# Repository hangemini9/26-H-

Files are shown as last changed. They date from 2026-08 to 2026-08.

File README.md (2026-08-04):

# 26-H- 车载平衡滚球控制系统

本仓库包含 2026 年电赛小车滚球控制系统的两套嵌入式固件。系统采用三主控协作架构：TI 底盘负责循迹与运动执行，MC02 负责云台、电机安全状态机与调度，并可与上位视觉计算单元联动。

> 注意：本项目涉及电机、锂电池和机械运动。首次上电或调试时，请断开电机供电、抬起驱动轮，并遵循各子项目中的接线与调试说明。

## 项目结构

| 目录 | 平台 | 职责 |
| --- | --- | --- |
| [`mspm0dache/`](mspm0dache/) | TI LP-MSPM0G3507 | 后驱差速底盘控制、编码器闭环、八路循迹传感器、OLED 显示，以及与 MC02 的串口通信。 |
| [`gimbal_MC02/`](gimbal_MC02/) | STM32H723 / 达妙 MC-Board02 | DM-J4310 云台控制、CAN 通信、USB CDC 调试接口、供电安全保护，以及与 TI/Jetson 的协议接口。 |

## 系统协作关系

```text
Jetson（视觉/上位机）
        │ USB CDC
        ▼
MC02（STM32H723） ───── UART ───── TI 底盘（MSPM0G3507）
        │ CAN                              │ PWM / 编码器 / I²C
        ▼                                  ▼
DM-J4310 云台电机                    差速驱动电机、循迹传感器、OLED
```

## 快速开始

### 底盘固件：`mspm0dache`

该项目使用 TI MSPM0 SDK 与 TI Clang 工具链。打开项目目录后，可在 VS Code 中选择构建任务，或使用：

```powershell
C:\ti\ccs\utils\bin\gmake.exe -C . -j4
```

详细的编译、下载、接线和首次标定说明见：

- [`mspm0dache/README.md`](mspm0dache/README.md)
- [`mspm0dache/COMMISSIONING.md`](mspm0dache/COMMISSIONING.md)
- [`mspm0dache/调试与标定指南.md`](mspm0dache/调试与标定指南.md)

### 云台固件：`gimbal_MC02`

该项目使用 CMake、Ninja 和 `arm-none-eabi-gcc`。在项目目录下执行：

```powershell
cmake --preset Debug
cmake --build --preset Debug
```

生成的调试产物位于 `build/Debug/`。调试下载使用 J-Link/Ozone；完整的接线与安全上电流程见：

- [`gimbal_MC02/README.md`](gimbal_MC02/README.md)
- [`gimbal_MC02/docs/MC02_WIRING_CHECKLIST.md`](gimbal_MC02/docs/MC02_WIRING_CHECKLIST.md)
- [`gimbal_MC02/docs/MC02_TI_PROTOCOL_V2.md`](gimbal_MC02/docs/MC02_TI_PROTOCOL_V2.md)
- [`gimbal_MC02/docs/JETSON_MC02_PROTOCOL_V3.md`](gimbal_MC02/docs/JETSON_MC02_PROTOCOL_V3.md)

## 协议与安全

- MC02 与 TI 底盘通过 UART 进行状态与任务控制通信。
- MC02 与云台电机通过 CAN 通信，并在上电、使能、故障和超时路径中实施保护。
- 底盘固件支持编码器、循迹传感器和通信链路的安全监测；异常时会停止并解除电机使能。
- 任何带电运动测试前，都应先完成无负载验证，并保留随时切断主电源的能力。

## 说明

各子项目的 README 是对应硬件与固件的权威操作说明。本文档用于介绍仓库整体结构；具体引脚、构建环境、协议帧和调参方法请以子项目文档为准。

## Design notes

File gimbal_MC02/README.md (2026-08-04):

# gimbal_MC02

达妙 DM-MC-Board02（STM32H723VGT6）控制 DM-J4310-2EC V1.2 的云台固件。
当前版本只面向桌面安全联调；视觉闭环、五项现场测试状态机和 TI 底盘通信均未启用。

## 当前固定配置

- 电机：DM-J4310-2EC V1.2，24 V，减速比 10:1
- 电机模式：位置速度模式
- CAN：经典 CAN、标准帧、1 Mbit/s
- 电机 CAN ID：`0x01`
- 电机 Master ID（反馈帧 ID）：`0xF1`
- MC02 电机 CAN：FDCAN1，PD0=RX、PD1=TX
- Jetson 链路：MC02 USB CDC；接口定义见
  [`docs/JETSON_MC02_PROTOCOL_V3.md`](docs/JETSON_MC02_PROTOCOL_V3.md)，build `2026073106` 已实现
- TI 底盘链路：接口定义见
  [`docs/MC02_TI_PROTOCOL_V2.md`](docs/MC02_TI_PROTOCOL_V2.md)，当前为 MC02 `2026080107`（按用户要求回退第二问，其他问保留）与 TI `2026080104`；五问题号路径、K6底盘软件动力许可、加减速斜坡前馈、停车后至少五秒达妙闭环保持和三秒最终稳定握手均已实现
- 编译：VSCode + CMake + Ninja + arm-none-eabi-gcc
- 调试/下载：J-Link + Ozone，SWD，4 MHz

完整接线和分阶段上电清单见
[`docs/MC02_WIRING_CHECKLIST.md`](docs/MC02_WIRING_CHECKLIST.md)。

依据 MC02 V1.1 原理图，PC14/PC13 分别控制 OUT1/OUT2 的高边电源。构建
`2026073008`在启动时明确保持两路关闭；OUT2始终关闭。常规接口只允许通过
`PWRARM 4310`后3秒内发送`PWRON`开启OUT1；人工调试开关启用时，
`CALRUN 4310 deg`会在同一安全状态机内完成一次受限上电测试。冷启动阶段会在保持转矩禁用的前提下
持续请求反馈，最多等待15秒。OUT1最多开启300秒，`STOP`、`PWROFF`、
任意故障、非JOG动作超时或复位都会立即关闭。JOG超时会失能并回到OBSERVE，
但保持同一供电周期的电机角度坐标。第一次必须断开电机，在空载状态下
分别验证OUT1关闭和开启电压。

## 编译

在 VSCode 中打开本目录，然后运行默认生成任务 `MC02: Build Debug`；或在终端运行：

```powershell
cmake --preset Debug
cmake --build --preset Debug
```

产物：

```text
build/Debug/gimbal_MC02.elf
build/Debug/gimbal_MC02.hex
build/Debug/gimbal_MC02.bin
```

全环路延迟测量必须使用独立的 `DelayTest` 预设，构建、Ozone 请求顺序和
强制空载验证见
[`docs/DELAY_TEST_FIRMWARE.md`](docs/DELAY_TEST_FIRMWARE.md)。该镜像不是比赛固件。

Ozone 打开 `gimbal_MC02.jdebug`，下载并复位运行。MC02 四针 SWD 插座按
说明书为：1=3.3 V/VTref、2=GND、3=SWCLK/PA14、4=SWDIO/PA13；该插座没有
NRST。不要用 J-Link 给 MC02 或电机供电。

## 上电安全行为

- 上电后状态为 `SAFE_IDLE`，不会自动使能电机。
- OUT1/OUT2上电默认关闭，OUT2没有开启路径。
- 常规OUT1供电需要`PWRARM 4310`与`PWRON`两步操作；人工调试`CALRUN`
  是常规 Debug 的受限例外。独立 `DelayTest` 构建另有专用 Ozone 解锁和
  空载确认流程；两者都只能在对应编译开关启用、SAFE_IDLE和无故障时启动。
- OUT1开启后等待500 ms，再发送5帧失能命令；完成前拒绝`OBSERVE`和运动。
- 启动时发送 5 帧失能命令，然后停止周期控制。
- 任何动作必须先收到新鲜 CAN 反馈，再执行一次性 `ARM`。
- `ARM` 只保留 3 秒，动作开始后立即失效。
- 当前角度被捕获为本次测试的局部零点。
- 最大相对角度固定为 ±10.0°。
- 位置速度模式的 `v_des` 固定为 0.20 rad/s。
- HOLD、STEP、SWEEP 分别在 15、3、6 秒后自动失能。
- 动作中 80 ms 没有电机反馈，立即进入故障并失能。
- 电机反馈状态不是 0（失能）或 1（使能）时，立即进入故障并失能。
- `STOP` 不需要解锁，任何时候都可执行。
- `STOP`、故障、非JOG动作超时和复位同时关闭OUT1；JOG超时失能并返回OBSERVE，
  OUT1仍受300秒总超时保护。

电机带电运动时不要让 CPU 停在断点；暂停 CPU 会同时暂停 CAN 心跳和软件保护。

## 桌面调试顺序

先固定电机和机构，保证 ±10° 内没有机械干涉，手能立即断开总电源。第一轮建议
先不装水管或移除钢球。

1. 在达妙助手确认模式、CAN ID、Master ID 和 1 Mbit/s。CAN Timeout 暂时保持 0。
2. 电机2+2插头保持断开，刷入 Debug ELF，复位后持续运行。
3. Ozone Watch 添加 `g_gimbal_debug`。应看到：
   - `build_id = 2026073008`
   - `state = 1`（SAFE_IDLE）
   - `fault = 0`
   - `can_tx_count` 启动后至少增加 5
   - `power_output_enabled = 0`
4. 第一次验证OUT1时保持电机2+2插头断开。发送`PWRARM 4310`后，在3秒内
   发送`PWRON`。测量空载OUT1应从约0 V变为主输入电压，并在300秒后自动回到
   约0 V。也要分别验证`PWROFF`和`STOP`能立即关闭OUT1。任一项不符合都不得
   连接电机。
5. 空载供电验证通过后，断电连接2+2电机线，再打开MC02 USB虚拟串口。
   USB CDC的终端波特率设置不影响链路，习惯上可选
   115200、8N1。依次发送：

```text
PWRARM 4310
PWRON
PING
OBSERVE
STATUS
```

`PWRON`后至少等待600 ms再发送`OBSERVE`，让电机启动并完成5帧失能命令。
`OBSERVE` 每 20 ms 发送位置速度模式失能帧来请求反馈，绝不使能电机。`STATUS` 应出现
`ONLINE=1`、`RX` 持续增加；失能时 `ERR=0x0`。若无反馈，不要继续动作测试。
如果 OBSERVE 收到状态1（使能）或任意故障反馈，固件会立即关闭 OUT1 并进入故障状态。

6. 第一次动作只做当前位置保持：

```text
ARM
HOLD
```

电机应转为绿色使能，但不应主动大幅转动；15 秒后自动失能。

7. 再做最小正反向测试：

```text
OBSERVE
ARM
STEP 0.5
OBSERVE
ARM
STEP -0.5
```

确认正负方向、反馈角度、机构刚度和电流正常后，才逐步增加到 1°、2°，最大 3°。

8. 最后才测试：

```text
OBSERVE
ARM
SWEEP 1.0
```

紧急停止命令：

```text
STOP
```

故障排除后发送 `CLEAR`，只会清故障并保持失能，不会恢复动作。

## 安装机构快速标定

坐标约定固定如下：钢球位置以中心 O 为零，朝电机所在的物理左端为正，朝铰链所在
的物理右端为负。水管角度则以水平为零、电机端升高为正、电机端降低为负。因此
当前机构的正电机偏移对应负水管角，并使钢球朝左侧正方向加速。日志中的
`CALRUN +deg`始终表示电机角度，不表示水管角度。
手机水平仪初测表明电机±45°对应水管倾角约∓2°，第一版映射可暂按
`水管角度≈-0.044×电机角度`使用，但必须保留为可调参数并由视觉闭环继续标定。

构建 `2026073008` 的下一项无球机构测试只使用一条命令：

```text
CALRUN 4310 45
```

发送前必须取出钢球、把水管置于水平、确认机构周围无人手或工具，并保证能够
随时断开总电源。该命令自行开启OUT1、等待电机反馈，提示后倒计时3秒，然后自动
以不超过0.20 rad/s执行`+45° -> 0° -> -45° -> 0°`，每段最多5秒并输出
起点、零点、目标和终点，最后失能并
关闭OUT1。任意阶段发送`STOP`都会立即中止并关闭OUT1。幅度参数只允许
0.1～45°。
构建`2026073008`修复了旧版运动循环仍二次限制在±10°的问题；本轮正确的两个
端点日志应接近`OFF=+785mrad`和`OFF=-785mrad`。若仍只出现约±174 mrad，
说明运行的不是修复后的固件，不得把它记为±45°测试通过。

这是纯人工桌面调试功能，由
`GIMBAL_ENABLE_MANUAL_CALRUN`控制。当前 Debug 调试构建为`1`；正式上车直接使用
`cmake --preset Vehicle`和`cmake --build --preset Vehicle`，该预设会可靠地把
`GIMBAL_MANUAL_CALRUN`设为`OFF`，使`CALRUN`只返回禁用提示。

如果15秒内仍没有电机反馈，流程会关闭OUT1并直接返回SAFE_IDLE，修复问题后可重新发送同一条命令，
无需先CLEAR。原有`ZERO/JOG/STEP/SWEEP`仍保留为底层单项诊断接口，并继续限制在
±10°和原有超时；只有人工CALRUN允许±45°和5秒单段。构建 `2026073008` 不改变
0.20 rad/s速度、80 ms反馈看门狗和断电保护。

先取出钢球，让底盘和水管处于水平状态。电机进入 `OBSERVE` 且反馈正常后发送：

```text
ZERO
STATUS
```

`ZERO`记录当前电机反馈为本次上电的水管水平零点。`STATUS`中的
`ZVALID=1`表示有效，`Z`是水平零点，`OFF`是当前电机相对水平零点的偏移。
随后发送：

```text
ARM
JOG 10
```

`JOG`始终以保存的水平零点为基准，而不是以每次动作前的位置为基准。
它仍然需要3秒内的`ARM`，并在3秒后失能、返回`OBSERVE`，但不切断OUT1，
以避免DM4310重启改变位置坐标。负向测试使用`JOG -10`。固件会自动报告
FROM、Z、TARGET以及动作结束时的P和OFF。为保证坐标一致，构建`2026073008`
会在STOP、故障、PWROFF、
300秒超时或其他OUT1掉电事件时自动作废零点，之后必须重新执行`ZERO`。
MC02复位同样会清除零点。

## Ozone 直接调参/触发

核心观测变量只有一个：`g_gimbal_debug`。状态和请求枚举见
`Core/Inc/gimbal_app.h`。

不要通过Ozone直接写PC14或GPIO寄存器开启OUT1。供电只允许使用USB命令。

直接触发云台动作时：

1. 将 `arm_key` 写为 `0xA55A5AA5`；
2. STEP/SWEEP 时把 `request_param_tenths_deg` 写成角度的 0.1° 单位，
   例如 `5` 表示 0.5°；
3. 最后写 `request`：STOP=1、OBSERVE=2、HOLD=3、STEP=4、SWEEP=5、
   CLEAR=6。

固件会消费并清零 `arm_key` 与 `request`。推荐先用 USB 命令完成首轮测试；
Ozone Watch 用于观察状态和后续快速调参。

## 目前还需要的实测信息

- 电机接到 MC02 的具体 FDCAN 口、CANH/CANL 和终端电阻实测；
- `STEP +10` 时水管实际顺/逆时针方向，用于冻结控制符号；
- 水管机械水平时的电机反馈角，以及本轮 ±45° CALRUN 端点的反馈角；
- build `2026072903`下OUT1空载关闭/开启/30秒超时/PWROFF/STOP的实测电压；
- 使用OUT1给DM4310供电时的6S电池电压、峰值电流和MC02输出温升。

构建 `2026073008` 保留已经验证的桌面 ±10° 限幅，并新增单指令标定，但这些量确认前仍不
启用视觉闭环，也不继续提高到 ±10° 以上。

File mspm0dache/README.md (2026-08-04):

# mspm0dache

MSPM0G3507 LaunchPad rear-drive differential-chassis firmware.

The chassis has two MG513XP28_12V drive motors at the rear and two passive
casters at the front. The first firmware is intentionally a safe commissioning
and calibration build. The current download path uses the LaunchPad onboard
XDS110 through its Micro-USB connector. Build 2026080104 implements all
eight button inputs and all five MC02 V2 question paths while keeping
standalone motion disabled. K1/K3/K4/K5 start their assigned chassis route
only after PREPARE/READY/START; K2 reports logical RUNNING while both PWM
outputs remain disabled for the stationary ball task. Q1 alone uses the
front line-sensor row as the final A datum through a bounded forward-align,
settle and reverse-marker sequence. Q3 stops after the measured 1.5 m A-B
straight; Q4/Q5 finish one lap without reversing. Q3/Q4/Q5 use a gentler
common-speed ramp while retaining fast steering correction. Q1 uses a
40-second safety timeout with a 143 RPM straight target and 110 RPM curve
floor, exactly 10% above the previous Q1 profile, to preserve the scored goal
of finishing within 20 seconds. No Q2-Q5 speed or ramp is changed.

中文上手说明见 [调试与标定指南.md](调试与标定指南.md)。
逐线硬件连接见 [接线指导.md](接线指导.md)。

Mechanical reference: [docs/R3X_chassis_320x240mm.pdf](docs/R3X_chassis_320x240mm.pdf).
The source PDF title says "four-wheel differential", but this firmware follows
the confirmed physical configuration of two driven rear wheels and two passive
front casters.

## Confirmed hardware

| Item | Configuration |
|---|---|
| MCU | LP-MSPM0G3507 |
| Motor driver | SeekFree dual-channel DRV8701E, PH/EN interface |
| Motors | 2 x MG513XP28_12V, nominal 1:28 gearbox |
| Encoders | 13 PPR quadrature Hall, measured left 1467/right 1468 counts/wheel revolution |
| Wheel diameter | 65.0 mm |
| Drive-wheel track | 214.2 mm, center to center |
| Front/rear axle spacing | 204.7 mm, metadata only |
| Tire contact width | 25.5 mm |
| Battery | 6S LiPo through regulated power conversion |
| Debug/download | LaunchPad onboard XDS110 through Micro-USB |
| Bluetooth | JDY-31 unplugged; UART0 code/config temporarily disabled |
| External button | SW1 active low on PA10/BP33 with MCU internal pull-up |
| Line sensor | Hiwonder LineFollower_8CH V1.0, 5 V supply, I2C address 0x5D |
| OLED | GM009605-class 128x64 I2C module, 3.3 V supply, address probe 0x3C then 0x3D |
| IMU | ICM42688 API placeholder only; disabled and no pins assigned |

## Build

Installed tool paths used by this project:

```text
C:\ti\mspm0_sdk_2_10_00_04
C:\ti\sysconfig_1.28.0
C:\ti\ccs\tools\compiler\ti-cgt-armllvm_5.1.1.LTS
C:\ti\ccs\utils\bin\gmake.exe
```

In VS Code, press `Ctrl+Shift+B` and select `Build MSPM0 (TEST_MODE)`, or run:

```powershell
C:\ti\ccs\utils\bin\gmake.exe -C . -j4
```

Run the complete offline verification (clean TEST_MODE build, release build,
configuration checks, ELF symbol checks, and memory report) with:

```powershell
C:\ti\ccs\utils\bin\gmake.exe -C . verify
```

The debugger-loadable ELF output is:

```text
ticlang\mspm0dache.out
```

To build and download the TEST_MODE firmware through the onboard XDS110,
select `Build and Flash MSPM0 (onboard XDS110)` in VS Code, or run:

```powershell
C:\ti\ccs\utils\bin\gmake.exe -C . flash
```

Keep all J101 jumpers in their factory-installed positions, connect only the
LaunchPad Micro-USB debug connector, and leave J102/J103 unused. CCS `DSLite`
performs the download. SEGGER Ozone does not control XDS110; use the CCS
debugger Expressions view when live writes to `g_test` are required. Source
editing and Makefile builds remain in VS Code.

### Live parameter tuning

The VS Code flash task exits after programming, so it cannot display or edit
live target variables. Run the VS Code task `Open CCS Live Tuning`; it opens
this same folder in the installed CCS 21 Theia application. In CCS:

1. Open Run and Debug.
2. Select `MSPM0G3507 XDS110 Live Tune` and start debugging.
3. If execution stops at `main`, press Continue.
4. Open the Expressions view and add only `g_test`.
5. Keep the target running and edit values in Expressions. Do not use
   breakpoints while motor power is connected.

The CCS launch configuration is `.theia/launch.json`. It loads
`ticlang/mspm0dache.out` through the onboard XDS110 and keeps the debug session
attached.

Build 2026080104 allows an intact, fresh sensor to report no active channel
during Q1's bounded straight reverse; sensor disconnect/staleness still
faults. The final marker still requires three simultaneous channels in three
fresh samples. TI also advertises commanded common acceleration/deceleration
in V2 status bits 10/11 so MC02 disables chassis feed-forward during steady
cruise. The OLED retries initialization once per second after runtime I2C
loss. Full clean verification results are recorded in `AGENT.MD`; they do not
replace powered floor commissioning.

The default build passes `TEST_MODE=1` and uses `-O0 -gdwarf-3` so global
variables remain easy to inspect. `gmake release` produces a build with the
test command executor disabled as `ticlang\mspm0dache_release.out`; that
build remains stopped because no production command source has been selected
yet.

## Pin assignment

| Function | MSPM0G3507 pin |
|---|---|
| Right motor PWM / DRV PWM1 | PA12 / TIMG0_CCP0 |
| Right motor direction / DRV DIR1 | PB4 |
| Left motor PWM / DRV PWM2 | PA13 / TIMG0_CCP1 |
| Left motor direction / DRV DIR2 | PB1 |
| Right encoder A/B | PB6 / PB7, J2 BP13/BP14, TIMG8 QEI |
| Left encoder A/B | PB16 / PB0, J2 BP11/BP12, GPIO both-edge IRQ |
| External button-panel SW1 | PA10 / BoosterPack 33, active low, internal pull-up |
| Temporarily unused | PA11 / BoosterPack 34 |
| Hiwonder line sensor SCL | PB2 / I2C1 SCL / BoosterPack 9 |
| Hiwonder line sensor SDA | PB3 / I2C1 SDA / BoosterPack 10 |
| OLED SCK/SDA | shared PB2/PB3 I2C1 bus with the line sensor |
| MC02 supervisor TX | PA8 / UART1 TX / J1_4 |
| MC02 supervisor RX | PA9 / UART1 RX / J14_3 |

The JDY-31 is unplugged and UART0 is not generated or linked in this build.
The retained `bluetooth.c/.h` and PC helper are inactive reference code.
Only button-panel SW1 is assigned; SW2-SW8, onboard S2, PA11, buzzer, and
ICM42688 control are unused. UART1 uses 115200 8N1 on PA8/PA9 for the MC02
binary supervisor link.

Expand `g_test.line` to observe `connected`, `sample_sequence`, `error_count`,
the eight-bit `state`, `active_count`, `line_lost`, `position_x1000`, and the
eight `analog[]` and `threshold[]` values. `position_x1000` is negative toward
S1/vehicle-left and positive toward S8/vehicle-right; one adjacent-sensor
spacing is 1000. Its value is invalid whenever `line_lost` is 1.
TEST_MODE build 2026080104 provides guarded competition line following as
mode 8. It uses `base_rpm` and `steering_kp`; `correction_rpm` and the two
wheel targets are telemetry. `steering_kd` damps residual heading after a
turn. `lap_phase` exposes the Q1 competition sequence, `lap_distance_mm`
reports total run travel, `turn_count`/`lap_yaw_deg` report the private
encoder-yaw turn estimate, and `finish_distance_mm` reports forward-align
distance in phase 3 and reverse distance in phase 5.
`marker_recent_state/count` expose the 120 ms reverse-search channel union as
diagnostics only. For Q1, a reverse marker candidate requires at least three
channels simultaneously active in three consecutive fresh samples,
preventing a drifting ordinary one/two-channel line from being accumulated
into a false marker. Q3/Q4/Q5
never enter the Q1 reverse phases. Their average/common wheel request uses
30 RPM/s for Q3 and 14 RPM/s for Q4/Q5 acceleration and deceleration slew;
their differential steering request retains a 300 RPM/s slew so gentler ball
handling does not make curve correction unresponsive. Q3 begins its gentle
stop at 1500 mm; Q4/Q5 use 70 RPM cruise and begin
the same stop after the existing two-turn/distance lap gate.

The OLED stopwatch starts when the accepted MC02 START reaches actual Q2
execution or, for a moving question, when the fresh-sensor gate succeeds and
the motor controller is armed. It updates once per second while running and
freezes when the chassis run ends. The value is rendered beside `TIME` as
three decimal seconds plus `S`; only the displayed three digits wrap after
999 seconds, while the internal timer never wraps there. Each change is
written as one complete four-character refresh. If three consecutive runtime
OLED writes fail, the display reconnects and redraws automatically once per second. A
K1-K5 press by itself no longer starts the displayed timer.
The first test must use raised drive wheels.
Sensor disconnect or stalled sampling removes drive immediately and faults
within 100 ms. Outside Q1 reverse, a line-only loss uses the last valid side
to search at reduced speed for at most 300 ms, then stops and disarms with
status -6. During Q1's bounded straight reverse, zero active channels does
not stop the reverse; the existing 400 mm/6 s bounds remain authoritative.
The first 50 ms of other line loss holds prior targets. Line position uses a
0.25 low-pass factor before curve-speed and PD calculation.
Before connecting PB2/PB3, power the sensor from its regulated 5 V rail with
common ground and measure idle SCL/SDA to ground. Connect them directly only
if both are no higher than 3.3 V; otherwise use a bidirectional I2C level
shifter. Do not power the sensor from J11 3V3.

## Debugger test workflow

Download with the VS Code XDS110 task above. For all commissioning control
and telemetry, attach CCS through the same onboard XDS110 and add only the
single expression `g_test`, then expand it. Set `duration_ms`, `target_rpm`,
and `left/right.kp/ki/kd` only while stopped. Encoder counts, RPM, error,
applied PWM, PID integral/output, button/countdown state, and safety faults
update inside the same structure. Line-sensor telemetry is under
`g_test.line`. The legacy
[mspm0dache.jdebug](mspm0dache.jdebug) file is retained only in case J-Link is
used again later.

Reset state is always:

```text
g_test.mode = 0
g_test.arm = 0
both PWM outputs = 0
```

For every motion command:

1. Set all parameters first.
2. Set `g_test.arm = 1`.
3. Set `g_test.mode` last.
4. The firmware consumes and clears `arm`.
5. It stops and disarms at completion or timeout.

Setting `g_test.mode = 0` also stops and disarms within the 10 ms task period.

| mode | Operation | Needs arm |
|---:|---|:---:|
| 0 | Stop/disarm | No |
| 1 | Stop and observe encoder telemetry | No |
| 2 | Reset both encoder totals | No |
| 3 | Right wheel only, positive open-loop PWM | Yes |
| 4 | Left wheel only, positive open-loop PWM | Yes |
| 5 | Both wheels positive open-loop PWM | Yes |
| 6 | Both wheels negative open-loop PWM | Yes |
| 7 | Both wheels closed-loop at `target_rpm` | Yes |
| 8 | Low-speed black-line following | Yes |

Motion results:

| status | Meaning |
|---:|---|
| -6 | Line sensor disconnected/stale for 100 ms, or line not reacquired within 300 ms |
| -5 | Required motor output never started or had the wrong sign |
| -4 | A required wheel encoder did not count or stopped counting |
| -3 | Bad parameter |
| -2 | Motion timed out |
| -1 | Motion requested without `arm = 1` |
| 0 | Idle |
| 1 | Running |
| 2 | Completed |
| 3 | Start pending / fresh line-sensor validation |
| 4 | Two-turn estimate unavailable; stopped by the 6.1 m distance fallback |

Open-loop diagnostic modes use a fixed 15% PWM. `duration_ms` defaults to
20000 ms and is frozen when a run starts. Modes 3-7 are hard-limited to
30000 ms; mode 8 is separately hard-limited to 120000 ms for the long test
track. Closed-loop modes require at least 2000 ms. Output has an absolute 40%
PWM safety cap that is not debugger-writable.

Modes 7 and 8 require both encoders to show continued progress in the commanded
direction. A missing, stalled, or oppositely signed encoder stops the run.
Each wheel's first 750 ms encoder window begins only after actual PWM has
cleared any direction-change hold. Once supervision starts, it never pauses:
zero output with no continued wheel motion still faults within the window,
and a non-zero wrong-sign output faults immediately. Mode 7 must verify both
encoders for at least one complete window before reporting success; see
`encoder_verified_mask`. Output readiness/direction uses `output_fault_mask`.

`g_test.status` is output telemetry, not a control input. The timeout and
fault state machine is private, so accidentally editing `status` in a debugger
cannot suspend protection.

For the first mode-8 test, raise the drive wheels and keep the sensor at its
calibrated gap above the track. Set `duration_ms = 5000`,
`line.base_rpm = 30`, and `line.steering_kp = 6`, then set `arm = 1` and set
`mode = 8` last. A centered S4/S5 line produces equal targets. Moving the line
toward S1 makes the left target lower and right target higher; moving it
toward S8 does the opposite. Removing the line must produce status -6 and
`motor_armed = 0` after the 300 ms directional-recovery window. Disconnecting
I2C or freezing samples must remove drive immediately and fault within about
100 ms. Only after these checks pass should a short floor test be attempted.

### MC02-supervised KEY1 formal-course control

Button-panel SW1 is connected to PA10/BP33, panel VCC to LaunchPad 3V3, and
panel GND to system GND. It is active low with the MSPM0 internal pull-up,
debounced for 40 ms, and polled by the 10 ms test task. Never power panel VCC
from 5 V.

1. Press/release KEY1 once. TI sends a debounced button event to MC02. It
   neither starts the stopwatch nor arms the motors at button time.
2. MC02 sends PREPARE, waits for TI READY, uses a three-second countdown
   interval, then sends START. For moving questions TI still requires five
   newly acquired valid line
   samples within 500 ms before arming.
3. Starting on the transverse bar, the first 100 mm commands equal left/right
   targets at the slow-start speed before normal centroid steering takes
   over. The run uses 30 RPM for the first second, a 55 RPM first-300-mm cap,
   143 RPM Q1 straight cruise and 110 RPM Q1 curve floor. The course model is two
   1500 mm straights plus two radius-500 mm semicircles: 6141.6 mm nominal
   centerline length. The Q1 safety timeout is 40,000 ms while the scored
   completion target remains 20 seconds.
4. After the two-turn/distance finish gate, TI follows 150-250 mm farther
   into the next straight at 60 RPM and requires eight fresh centered
   one/two-channel samples. It commands true zero and waits for both wheels
   to settle below 2 RPM, then reverses with equal 25 RPM targets. A is
   accepted only after at least three channels are simultaneously active in
   three consecutive fresh sensor samples. The 120 ms union remains visible
   for diagnosis but does not grant stop authority. Failure
   to find A within 400 mm or 6 seconds stops as a route timeout.
5. Q1 route completion, MC02 SAFE_STOP, a fault, or a link-loss stop freezes
   the displayed integer seconds. OLED failure never grants or removes motor
   authority.

`STANDALONE_KEY1_START=0` makes PREPARE/READY/START the only motion
authority. K1-K5 select the five internal questions. K6 toggles a software
chassis-power permission only while TI/MC02 are online and idle: OLED
`PWR 0` blocks Q1/Q3/Q4/Q5, while `PWR 1` permits their later START.
Q2 remains stationary and works with `PWR 0`. SAFE_STOP, K7, K8, faults and
link loss all restore `PWR 0`; this is not a physical 12 V disconnect.
K7 is normal stop/reset and K8 is the latched emergency stop. The physical
motor-power disconnect remains mandatory during first communication tests.

Expand `g_test.mc02` for compact link telemetry: `online`, `state`, `fault`,
`run_id`, `last_command_id`, `question_id`, and RX/CRC/TX counters.

### JDY-31 Bluetooth status

The JDY-31 module has been unplugged at the user's request. UART0 and all
Bluetooth start/heartbeat/status handling are excluded from build 2026073006.
The source and helper script are retained only so Bluetooth can be restored
later. PA10 is now SW1 and must not be connected to the JDY-31 at the same
time.

The motor layer also guards direction reversal: PWM is removed, the wheel is
given at least 1000 ms to coast and must then read below 2 RPM, then the DIR
line receives a further 10 ms setup interval before PWM can resume. Encoder
feedback can never shorten the fixed 1000 ms interval.

## Mandatory first commissioning order

Read [COMMISSIONING.md](COMMISSIONING.md) before connecting motor power.
The short version is:

1. Keep the DRV8701E motor power disconnected and verify reset PWM is zero.
2. Power both encoders from verified 5 V, pass all four push-pull A/B outputs
   through proper 5 V-to-3.3 V level translation, and measure each MCU-side
   high level before connecting it to the MCU.
3. Calibrate left and right counts per wheel revolution independently.
4. Verify each PWM/DIR channel with a scope.
5. Apply regulated 12 V, lift both wheels, and start at 10-15% PWM.
6. Tune PID only after encoder scale and direction are correct.
7. Calibrate effective track using repeated in-place turns.

Do not halt the CPU at a breakpoint while motor power is enabled. A halted
core cannot execute the timeout, and a PWM timer may stop while its output is
high. Use live Expressions updates without breakpoints for powered testing.

## Source map

- `chassis_config.h`: geometry, encoder placeholders, signs, safety limits.
- `motor.c/.h`: PH/EN output, QEI/GPIO encoders, filtered RPM, PID, arming.
- `chassis.c/.h`: differential kinematics and odometry conversions.
- `test_mode.c/.h`: one-shot debugger command interface and telemetry.
- `imu.c/.h`: disabled ICM42688 placeholder.
- `mspm0dache.syscfg`: authoritative peripheral and pin allocation.
- `AGENT.MD`: handoff state for future agents and conversations.

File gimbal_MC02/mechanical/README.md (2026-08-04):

# DM4310 end-drive crank R50 V1

`DM4310_CRANK_R50_M8_V1.stl` is the recommended replacement for the supplied
low-eccentricity integral-rod parts.

## Frozen dimensions

- output hub: 35 mm diameter;
- part thickness: 10 mm;
- four motor mounting holes: 3.3 mm diameter on a 27 mm pitch circle;
- follower-pin eccentricity: 50 mm;
- follower-pin hole: 8.2 mm diameter;
- follower boss: 21 mm diameter;
- nominal hinge-to-drive distance: 220-230 mm;
- intended usable pipe tilt: approximately +/-10 degrees;
- initial motor travel for the mechanism: approximately +/-55 degrees from
  the installed neutral, subject to ball-free hardware verification.

The four mounting-hole centers are at radius 13.5 mm and angles 60, 120, 240,
and 300 degrees. This is equivalent to approximately
`(x,y)=(+/-6.75,+/-11.69) mm`, measured from the motor-output center.

## Required follower hardware

Do not print a long cantilever rod as part of the crank. Use:

- one M8 steel shoulder bolt or smooth 8 mm steel shaft;
- preferably two 688 bearings (8 x 16 x 5 mm) as the free follower roller;
- spacers and a locknut so the roller contact plane is about 18-20 mm in
  front of the printed crank;
- an upper keeper with 1-2 mm free clearance above the 20 mm OD pipe so the
  pipe cannot leave the follower during vehicle vibration.

If the hinge axis passes through the pipe centerline, a 16 mm OD follower
requires the motor axis to be about 18 mm below the hinge axis when the pipe
is horizontal and the crank points horizontally. Recalculate this height if
the final follower outside diameter or hinge offset changes.

## Printing

- print flat with the 10 mm thickness in Z, as stored in the STL;
- PETG, PA, or another tough material is preferred over brittle PLA;
- use at least 6 walls and 60% infill; use 100% infill around the follower
  boss if the slicer supports modifier regions;
- inspect all four motor holes and the M8 follower hole before installation;
- do not perform the first powered test with a ball installed.

The generator is `generate_dm4310_crank.py`. It requires `trimesh`, `shapely`,
and `mapbox_earcut`.

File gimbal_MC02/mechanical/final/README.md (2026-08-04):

# Final printed gimbal crank

User-frozen on 2026-07-30:

```text
PITCH_FINAL_R15P45_R3_20260730.STL
```

Original source:

```text
C:\Users\Han\Desktop\dIANSAI\PITCH_NEW_RPLUS7_R3_CONTAINED.STL
```

Integrity:

```text
size:   768984 bytes
SHA256: 010919C1A376811A5C7BEDD237305554FC9CF96A3D4154B04B5BBF57FD02E3F5
```

The source and project backup were byte/hash verified identical.

## Measured STL geometry

- binary STL, 15,378 triangles;
- one connected watertight component;
- overall bounds approximately 49 x 75 x 49 mm;
- circular mounting base diameter: 49 mm;
- four mounting holes: diameter 3.2 mm on a 27 mm pitch circle;
- integral follower rod: diameter 12 mm;
- follower-axis eccentricity from motor axis: **15.45 mm**;
- R3 contained transition is present;
- mesh volume: approximately 17,263 mm^3.

This is the final physical print selected by the user. Earlier 25 mm and
50 mm crank proposals and `mechanical/DM4310_CRANK_R50_M8_V1.stl` are
superseded and must not be used for firmware geometry.

## Firmware constants still pending installation

Use the fixed crank radius:

```text
crank_radius_mm = 15.45
```

Do not finalize the motor-to-pipe mapping until these installed values are
measured:

- hinge-axis to follower contact distance `L`;
- motor feedback angle at a level pipe;
- installed motion sign;
- usable motor-angle endpoints before contact loss or collision.

Installed measurements reported on 2026-07-30:

- DM4310 axis is 1 mm above the hinge axis;
- pipe midpoint to follower station is 115 mm;
- pipe midpoint to hinge axis is 133 mm;
- direct hinge-to-follower distance was separately reported as 236 mm.

The two midpoint dimensions imply 248 mm, which conflicts with 236 mm by
exactly the nominal 12 mm follower diameter. Do not use either as the final
`L` until the hinge-axis to DM4310-output-axis center distance is directly
remeasured. The physical pipe endpoints are +/-125 mm from O and the scored
positions are +/-50 mm.

The geometric absolute pipe-angle limit is
`asin(15.45 / L)`. Representative values are approximately:

| L | Absolute geometric limit |
|---:|---:|
| 180 mm | 4.92 deg |
| 220 mm | 4.03 deg |
| 230 mm | 3.85 deg |

No firmware behavior is verified merely by freezing this STL.

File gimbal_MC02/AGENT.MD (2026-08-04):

# gimbal_MC02 canonical handoff

Last updated: 2026-08-01

## 2026-08-01 user-requested rollback from build 0108 to 0107

- At the user's explicit request, the untested build `2026080108` Q2 energy
  schedule was removed and MC02 Vehicle was restored exactly to Q2 build
  `2026080107`: 350 ms positive breakaway, 1.8-degree stationary positive
  request, no forced raw-30-mm brake, no centre-crossing drive floor, and a
  20 mm final-capture entry with the +1.0-degree negative drive cap.
- Q1 and accepted Q3-Q5 behavior remain unchanged. TI stays at build
  `2026080104`; Jetson V3 and TI V2 packet formats and meanings are unchanged.
  Full clean Debug/Release/Vehicle/DelayTest verification passed at
  111340/716/13964, 69876/712/13952, 69588/712/13952 and
  113932/716/14028 text/data/BSS bytes. Powered behavior remains to be tested.

## 2026-08-01 Q2 data-driven asymmetric energy schedule

- MC02 Vehicle build `2026080108` changes only Q2. TI remains build
  `2026080104`; Q1 and the accepted Q3-Q5 controller/route behavior are
  unchanged, and neither Jetson V3 nor TI V2 packets changed.
- The supplied multi-run extraction contains eight active Q2 attempts. Two
  never moved despite a -2.0-degree request. Of the other six, the positive
  peak median was +94.7 mm and five exceeded +60 mm. Negative-leg braking
  first appeared at a median raw position of +28.4 mm; the negative trough
  median was only -34.6 mm, and only one run reached -50 mm. Clean near-100%
  valid-vision runs show the same failure, so it is not only vision dropout.
- Reliable positive breakaway is restored to -2.0 degrees for 400 ms. Once
  raw position reaches +30 mm at >=10 mm/s, +2.0-degree braking is forced,
  without shortening the existing raw-or-projected +50 mm waypoint switch.
  A stationary ball inside the last 7 mm receives only a -0.8-degree crossing
  nudge; outside it retains the full -2.0-degree anti-stall request.
- On return, after the existing +1.5-degree/250 ms pulse, at least +0.6 degree
  of drive is retained while the ball is moving negative but still has raw
  x>0. Normal Kd authority resumes after the centre crossing. Final capture
  is delayed from 20 mm to 10 mm final error; the +1.0-degree drive cap,
  +30 mm/s rebound rule, 1 s settle, 5 s earliest completion and 15 s safety
  timeout remain unchanged.
- Full clean Debug/Release/Vehicle/DelayTest verification passed at
  111484/716/13964, 70028/712/13952, 69748/712/13952 and
  114084/716/14028 text/data/BSS bytes. Powered behavior is unverified until
  the user flashes and tests the Vehicle ELF.

## 2026-08-01 Q2 small asymmetric trim after selective rollback

- MC02 Vehicle build `2026080107` changes only Q2 on top of the selective
  build-0101 rollback. Q1 and accepted Q3-Q5 behavior remain unchanged; TI
  stays at build `2026080104`, and Jetson V3/TI V2 are unchanged.
- To reduce the reported small positive overshoot, the stationary positive
  request is 1.8 instead of 2.0 degrees and the existing 2.0-degree positive
  breakaway pulse is shortened from 400 to 350 ms. Waypoint switching remains
  the unchanged raw-or-delay-projected +50 mm rule.
- To prevent the negative leg slowing too early, the permanent final-capture
  latch moves from 30 to 20 mm final error and the post-launch positive drive
  cap rises from 0.8 to 1.0 degree. The +30 mm/s rebound threshold, full
  bounded braking authority, 1 s final settle, 5 s earliest completion and
  15 s safety timeout remain unchanged.
- Full clean Debug/Release/Vehicle/DelayTest verification passed at
  111340/716/13964, 69876/712/13952, 69588/712/13952 and
  113932/716/14028 text/data/BSS bytes. Powered behavior is unverified until
  the user flashes and tests the Vehicle ELF.

## 2026-08-01 selective Q2 rollback to build 0101 behavior

- At the user's explicit request, only the MC02 stationary Q2 controller was
  restored to the behavior identified as build `2026080101`. Q1 and the
  accepted current Q3-Q5 route/controller behavior are intentionally retained;
  this is not a whole-repository rollback. The Vehicle image reports build
  `2026080101`, and the current user-restored TI image remains `2026080104`.
- Q2 again switches from +50 mm to -50 mm when either raw position or the
  bounded delay projection reaches +50 mm. The later raw-30-mm forced brake,
  crossing nudge, staged -25/-40 mm damping and repeated final-friction pulses
  are removed.
- The negative leg again uses one +1.5-degree/250 ms launch pulse, a +0.8
  degree positive-drive cap below +30 mm/s rebound speed, full bounded rebound
  braking above that threshold, and a permanent 30 mm final-capture latch that
  limits only non-braking drive to 0.6 degree. Final settle is the earlier
  1000 ms gate held through the five-second checkpoint; the 15000 ms safety
  timeout remains.
- Jetson V3 and TI V2 versions, packets, fields and meanings are unchanged;
  neither Jetson nor TI needs rebuilding. Full clean Debug/Release/Vehicle/
  DelayTest verification passed at 111340/716/13964, 69884/712/13952,
  69596/712/13952 and 113932/716/14028 text/data/BSS bytes. Powered behavior
  remains unverified until the user flashes and tests the Vehicle ELF.

## 2026-08-01 Q2 staged return damping and persistent capture

- MC02 Vehicle build `2026080106` pairs with current TI TEST_MODE build
  `2026080106`. The change is confined to Q2; Q1 and the accepted Q3-Q5
  controller/route behavior are unchanged.
- The supplied three-file extraction contains eight complete build-0105 Q2
  attempts. Positive peak median/maximum were +62.8/+85.2 mm and only one
  attempt stayed at or below +60 mm. The first negative trough median/worst
  were -75.0/-107.0 mm, the median first rebound span was 80.9 mm, and the
  ball crossed -50 mm a median eight times. At the alternating extrema the
  recorded pipe request repeatedly reached -2/+2 degrees, identifying a
  controller-created saturated limit cycle rather than a link failure.
- Positive full braking now starts from raw +30 mm whenever velocity is at
  least +10 mm/s; the noisy projected +42 mm gate is removed. Raw +50 mm is
  still the only waypoint switch, and the existing stationary nudge remains
  available if braking stops the ball short.
- Negative braking remains blocked only above projected -25 mm. From -25 to
  -40 mm it is admitted with a 0.8-degree cap; at and beyond -40 mm the whole
  negative-leg command is bounded to +/-1.2 degrees. The existing +1.5-degree
  250 ms transition pulse is unchanged and executes outside that cap.
- Final capture latches permanently on the first entry within 10 mm of
  -50 mm. It retains the +/-1.2-degree negative-leg envelope above 60 mm/s,
  then clamps both signs to +/-0.8 degree below that speed. It cannot exit and
  restore the measured +/-2-degree relay behavior; the existing bounded
  stationary friction releases and 2 s visible settle gate remain.
- Jetson V3 and TI V2 fields, versions, lengths and meanings are unchanged;
  neither Jetson nor TI source needs modification for this MC02 update.
  Full clean Debug/Release/Vehicle/DelayTest verification passed at
  112228/716/13988, 70468/712/13976, 70172/712/13976 and
  114836/716/14052 text/data/BSS bytes. Powered behavior remains unverified
  until the user flashes and tests the Vehicle ELF.

## 2026-08-01 Q2 asymmetric approach scheduling

- MC02 Vehicle build `2026080105` pairs with unchanged TI TEST_MODE build
  `2026080105`. The change is confined to Q2: Q1 and the already accepted
  Q3-Q5 controller/route behavior are unchanged.
- The positive leg reduces its stationary anti-stall request from 2.0 to
  1.6 degrees. Once raw position is at least +30 mm, a delay-projected
  position of +42 mm requests the existing full +2-degree brake. Only the
  raw +50 mm crossing still changes the target, so the printed waypoint is
  not shortened. If that earlier brake leaves the ball stationary within the
  final 7 mm before +50 mm, a smaller -0.8-degree crossing nudge prevents a
  deadlock without restoring the full launch command.
- On the negative leg, when the ball is moving toward -50 mm but its delay
  projection is still above -40 mm, a negative-pipe Kd request is held at
  level instead of braking the ball around +30..+40 mm. The post-launch
  positive-pipe drive cap is raised from 0.8 to 1.2 degrees so the existing
  static-friction floor is not immediately clipped. At/after projected
  -40 mm, final braking, capture hysteresis and rebound authority are the
  existing build-0104 behavior.
- Q2 explicitly forces the TI chassis-acceleration term to zero. Q3-Q5 retain
  the existing gated feed-forward unchanged. Fixed +/-2-degree pipe,
  +/-45-degree motor, 3 rad/s slew, 5-second score diagnostic, 15-second
  safety timeout and all immediate fault cutoffs remain authoritative.
- Jetson V3 and TI V2 packet versions, fields, lengths and meanings are
  unchanged; neither Jetson nor TI source needs an update. Offline build
  verification passed for Debug, Release, Vehicle and DelayTest at
  112236/716/13988, 70436/712/13976, 70148/712/13976 and
  114836/716/14052 text/data/BSS bytes. Powered Q2 behavior is not claimed
  until the user flashes and tests the Vehicle ELF.

## 2026-08-01 Q4/Q5 thirty-percent speed-profile reduction

- MC02 Vehicle build `2026080104` pairs with TI TEST_MODE build
  `2026080103`. TI changes only Q4/Q5: cruise 100 -> 70 RPM and common-wheel
  acceleration/deceleration 20 -> 14 RPM/s. Q3 stays at 100 RPM/30 RPM/s;
  Q1, Q2 and all Q2 build-2026080103 control behavior are unchanged.
- MC02's question-specific Q4/Q5 immediate chassis feed-forward floor is
  matched from 0.070 to 0.048 m/s2. The 500 ms feed-forward tail, 30000 ms
  scored total timeout, TI 8000 ms gentle-stop guard, five-second normal
  post-route gimbal hold and every immediate safety cutoff are unchanged.
- Jetson V3 and TI V2 packet versions, lengths, offsets and meanings are
  unchanged; no Jetson upload is required. Both MC02 and TI images require
  flashing. Clean Debug, Release, Vehicle and DelayTest verification passed
  at text/data/BSS sizes 112076/716/13988, 70300/712/13976,
  70004/712/13976 and 114676/716/14052 bytes respectively. Powered Q4/Q5
  timing remains unverified.

## 2026-08-01 Q2 measured-waypoint braking and visible final stop

- MC02 Vehicle build `2026080103` pairs with the unchanged TI TEST_MODE build
  `2026080102`. The three-second TI/MC02 start countdown remains unchanged and
  Q2 elapsed time still begins only when TI acknowledges RUNNING. Jetson V3
  and TI V2 packet versions, lengths, offsets and meanings are unchanged.
- Q2 prediction no longer switches to the return leg before the raw ball
  position reaches +50 mm. It instead requests the existing bounded +2-degree
  braking angle when the 125 ms projection reaches +50 mm; the raw crossing
  alone starts the existing +1.5-degree/250 ms negative launch. This addresses
  the five-run +57.3/+80.6/+81.2/+68.7/+72.6 mm positive peaks without
  permitting a turn short of the printed waypoint.
- Negative final capture enters at 10 mm error and exits at 15 mm instead of
  latching permanently inside 30 mm. The launch pulse is separate from two
  final stationary friction releases: +1.0 then +1.2 degrees for 150 ms, with
  a 200 ms observation cooldown. Active friction release bypasses only the
  0.6-degree capture clamp; the fixed +/-2-degree pipe, +/-45-degree motor and
  3 rad/s slew envelopes remain authoritative. No motor zero is retained
  across OUT1 power cycles.
- Q2 completion now requires raw final error <=10 mm and a position span <=2
  mm continuously for 2000 ms; worst-case drift over that window must be <=3
  mm/s. Five seconds is a latched diagnostic only and never cuts torque; the
  unchanged 15000 ms Q2 safety timeout remains authoritative. New Ozone fields
  expose final capture, stop drift, elapsed time, score-deadline miss and
  friction cooldown.
- Q3-Q5 controller parameters and TI source are unchanged. Clean compilation
  passed for Debug, Release and DelayTest; powered behavior is not yet claimed.

## 2026-08-01 substantially slower Q3-Q5 ramps and feed-forward tail

- MC02 Vehicle build `2026080101` pairs with TI TEST_MODE build
  `2026080102`. Q3 common acceleration/deceleration is 30 rpm/s; Q4/Q5 use
  20 rpm/s. Cruise speed, steering slew and scored total timeouts are unchanged.
- MC02 uses matched immediate feed-forward floors of 0.10 m/s2 for Q3 and
  0.07 m/s2 for Q4/Q5. After TI's commanded-ramp flag clears, the last bounded
  feed-forward decays linearly over 500 ms instead of disappearing at once.
  `ti_chassis_accel_tail_remaining_ms` exposes that interval in Ozone.
- TI's local gentle-stop guard is 8000 ms so the deliberately slow Q4/Q5
  deceleration can complete; the 30-second total deadline remains unchanged.
  Normal route completion still enters the five-second DM4310 hold. Actual
  fault, stop, link-loss and vision-loss paths remain immediate.
- Jetson V3 and TI V2 packet layouts and meanings remain unchanged. Full clean
  offline verification passed: Debug 111292/716/13956, Release
  69860/712/13952, Vehicle 69548/712/13952 and DelayTest 113892/716/14020
  text/data/BSS bytes. Powered behavior is not yet claimed.

## 2026-08-01 TI-only delayed OLED initialization

- TI TEST_MODE build `2026080101` delays its first external-OLED transaction
  by 1000 ms and retains one-second retry/redraw. MC02 Vehicle remains build
  `2026073126`; TI V2 and Jetson V3 are unchanged, so MC02 and Jetson do not
  require source changes for this display hardening.

## 2026-08-01 gentler Q3-Q5 common-speed ramps

- MC02 Vehicle build `2026073126` pairs with TI TEST_MODE build `2026073119`.
  Q3-Q5 common-wheel acceleration and deceleration are reduced from 50 to
  40 rpm/s; MC02's immediate phase-gated feed-forward floor is matched from
  0.17 to 0.14 m/s2.
- Cruise RPM, steering slew, route distances, scored total timeouts, the
  five-second post-stop DM4310 hold and all immediate safety cutoffs are
  unchanged. Jetson V3 and TI V2 formats are unchanged.
- Clean Debug/Release/Vehicle/DelayTest verification passed at
  111020/716/13940, 69684/712/13936, 69372/712/13936 and
  113612/716/14004 text/data/BSS bytes. Powered behavior remains unverified.

## 2026-07-31 ramp feed-forward floor and five-second post-stop hold

- MC02 Vehicle build `2026073125` keeps Jetson V3 and TI V2 packet versions,
  lengths, offsets and meanings unchanged. No Jetson file needs updating.
- While exactly one existing TI common-speed ramp flag is active, MC02 now
  applies the signed 0.17 m/s2 acceleration implied by TI's 50 rpm/s slew
  immediately. The wheel-RPM derivative may raise that estimate up to the
  existing 0.40 m/s2 clamp; it can no longer erase the known ramp because of
  its first-window delay or low-speed deadband. Steady cruise still resets
  feed-forward exactly to zero.
- For Q3-Q5, route completion keeps the DM4310 powered in competition closed
  loop for at least 5000 ms after chassis stop. The existing 5 mm / 30 mm/s / 
  3000 ms continuous settle gate can extend the hold, with the unchanged
  15000 ms deadline. STOP, K7/K8, link loss, invalid vision and motor faults
  remain immediate cutoffs.
- `ti_route_hold_remaining_ms` exposes the mandatory hold countdown in Ozone.
  Clean Debug/Release/Vehicle/DelayTest verification passed at
  111020/716/13940, 69684/712/13936, 69372/712/13936 and
  113612/716/14004 text/data/BSS bytes. Powered hardware behavior is not yet
  claimed.

## 2026-07-31 TI OLED-only build increment

- TI TEST_MODE build `2026073117` changes only its local OLED refresh and
  telemetry. MC02 remains Vehicle build `2026073124`; TI V2 and Jetson V3
  packet versions, layouts and meanings are unchanged, so no MC02 or Jetson
  rebuild is required for the display fix.
- The MC02 board repository contains legacy BMI088 driver and Mahony sources,
  and the original IOC assigns SPI2 plus accelerometer/gyro chip selects, but
  the current competition CMake target deliberately does not compile or
  initialize that path. Current chassis feed-forward therefore remains the
  gated TI wheel-encoder speed derivative, not an IMU measurement.

## 2026-07-31 gated chassis feed-forward and Q1 40 s supervisor

- MC02 Vehicle build `2026073124` keeps the Jetson V3 and TI V2 packet
  versions, lengths and offsets unchanged. TI V2 reserved flag bits 10/11
  now mean intentional common-wheel acceleration/deceleration. MC02 estimates
  and applies chassis acceleration only while exactly one gate is asserted,
  the TI state is RUNNING and motor output is enabled.
- During steady cruise the estimator is reset and chassis feed-forward is
  exactly zero. Samples below 0.05 m/s2 or whose sign contradicts the asserted
  gate are rejected. Existing acceleration, angle and slew limits still clamp
  every command.
- Q1's MC02-side expected supervisor window is now 40000 ms, matching TI
  build `2026073117`; the competition scoring target remains <=20 s. Q2-Q5
  timing and the existing three-second final stability requirement are
  unchanged.
- Clean Debug/Release/Vehicle/DelayTest verification passed. Text/data/BSS
  are 110844/716/13940, 69556/712/13928, 69244/712/13928 and
  113444/716/14004 bytes. No flash or powered hardware result is claimed.

## 2026-07-31 moving-question chassis feed-forward and 3 s final hold

- MC02 Vehicle build `2026073123` keeps the Jetson V3 packet version,
  messages, lengths and field meanings completely unchanged. It consumes the
  already-frozen TI V2 `CHASSIS_STATUS.left_rpm_x10/right_rpm_x10` fields,
  whose corrected sign is vehicle-forward positive. The 20 Hz average wheel
  speed is differentiated over a 50 ms-or-longer interval, low-pass updated
  with alpha 0.5 and clamped to +/-0.40 m/s2. The estimate is invalidated
  whenever TI motor output clears, chassis state leaves RUNNING or V2 status
  is stale.
- Q3-Q5 now use
  `alpha_pipe = -(1.4*a_des + a_chassis_x)/g`. The installation mapping is a
  bounded Ozone tuning field `control_chassis_forward_to_x_sign`, initialized
  to +1; -1 selects the opposite installed pipe direction and 0 disables the
  feed-forward for A/B comparison. New diagnostics expose both TI RPM values,
  derived acceleration and feed-forward pipe millidegrees. The existing
  +/-2-degree pipe, +/-45-degree motor and 3 rad/s motor-slew envelopes still
  clamp the combined request. Q2 sees zero chassis feed-forward because TI
  keeps its motor-output flag clear.
- On Q3-Q5 `ROUTE_COMPLETE`, MC02 sends the existing Jetson route-complete
  event but retains gimbal closed loop while TI stays disarmed in state 5.
  Whole-system completion now requires raw target error <=5000 um and the
  fixed-window control velocity <=30000 um/s continuously for 3000 ms. Any
  invalid/stale sample or threshold violation resets the timer. A 15000 ms
  post-route bound stops without reporting successful completion. Q1 and Q2
  completion behavior is unchanged.
- Full clean Debug/Release/Vehicle/DelayTest verification passed. Text/data/
  BSS are 110684/716/13940, 69476/712/13928, 69164/712/13928 and
  113284/716/14004 bytes. This is offline evidence only. Before a floor run,
  verify build `2026073123`, V2 RPM signs, feed-forward sign at a slow start,
  and the 0-to-3000 ms continuous settle timer. Jetson does not need a code
  upload for this change.

## 2026-07-31 Q2 Step B + Step B2 velocity observation

- After the user hardware-confirmed the Step A baseline, Vehicle build
  `2026073121` implements only the requested Step B and Step B2 observation
  changes. MC02 now ignores the Jetson velocity field for control and derives
  velocity from position samples over a fixed 70 ms target window, accepting
  actual spans from 50 to 120 ms. Samples are keyed by the Jetson-frame MC02
  receive timestamp, so a faster control loop cannot insert duplicates.
- The two Q2 anti-stall drive-floor mechanisms no longer use a single-frame
  absolute-velocity threshold. Their three directional admission branches
  now require raw position to remain inside the existing 2 mm band for
  120 ms. The motion window is independent of the breakaway-pulse stall
  detector. The capture clamp's existing 20 mm/s condition and the final
  settle gate's 60 mm/s condition remain unchanged.
- Ozone debug adds `control_velocity_window_ms` and `q2_stationary_ms`
  immediately after `control_velocity_um_s`. Valid sample receipt updates
  these observation-only fields even before Q2 starts, allowing the required
  no-motion commissioning check; receive-time guards prevent the subsequent
  control call from inserting the same sample twice. On invalid/stale vision, the
  velocity history, filtered velocity and stationary window are cleared;
  an invalid span while vision remains valid retains the previous filtered
  velocity so Kd does not disappear for one control cycle.
- No acceleration predictor, curve speed schedule, integral term or higher
  motor slew was added. The fixed +/-2-degree pipe and +/-45-degree motor
  envelopes, 3.0 rad/s slew, Kp/Kd 4.0/2.5, targets, breakaway parameters,
  Step A rebound rule, timeouts and every immediate safety cutoff are
  unchanged.
- Full clean Debug/Release/Vehicle/DelayTest verification passed. Text/data/
  BSS are respectively 109276/716/13876, 68484/712/13872,
  68212/712/13872 and 111876/716/13940 bytes. This is offline compile/static
  evidence only. Before K2, hardware must confirm build ID `2026073121`, a
  70..110 ms reported velocity window, stationary velocity within about
  +/-10000 um/s, and `q2_stationary_ms` increasing at rest then immediately
  resetting when the ball is nudged.

## 2026-07-31 Q2 Step B/C rollback

- At the user's request, the unflashed build-3121 Step B/C estimator and
  acceleration-prediction changes were removed. The current source and
  Vehicle artifact are restored to the hardware-confirmed Step A baseline,
  build `2026073120`.
- MC02 again uses the Jetson velocity when its valid flag is set, retains the
  original control-task-time fallback, projects position with bounded
  constant velocity `x+v*T`, and uses measured velocity in Kd and the existing
  energy-sign test. The three build-3121-only Ozone fields were removed.
- The Step A `GIMBAL_Q2_REBOUND_BRAKE_UM_S=30000` behavior remains: positive
  rebound at or above 30 mm/s regains the existing +2-degree braking
  authority; below it, the +0.8-degree positive drive cap remains.
- Full clean Debug/Release/Vehicle/DelayTest verification passed. Text/data/
  BSS are exactly the recorded Step A values: 108724/716/13780,
  68212/712/13776, 67884/712/13776 and 111316/716/13844 bytes. This is
  compile/static evidence and not a new powered-hardware claim.

## 2026-07-31 Q2 Step A rebound-braking authority fix

- The external improvement directive identified a sign-dependent authority
  bug in the build-3119 negative-leg drive cap. After the transition pulse,
  all positive-pipe requests were capped at +0.8 degree. That is correct while
  the ball moves toward -50 mm, but once the ball rebounds toward positive
  position the same positive pipe angle is braking and the unconditional cap
  prevents full energy removal. In `run_1848.csv`, representative trough-to-
  rebound pairs are -85.8 to -3.4 mm, -82.1 to -8.9 mm and -67.9 to -35.8 mm.
- Vehicle build `2026073120` adds
  `GIMBAL_Q2_REBOUND_BRAKE_UM_S=30000`. With no active launch pulse, the
  +0.8-degree positive-pipe cap remains while filtered measured velocity is
  below +30 mm/s. At +30 mm/s or faster positive rebound, positive pipe angle
  is braking and may use the existing full +2.0-degree envelope. The threshold
  avoids switching authority on the measured high-frequency velocity noise.
- This Step A build deliberately does not implement the requested Step B/C
  velocity-window and acceleration-prediction changes. It must first receive
  3..5 hardware CSV runs so the rebound-only effect stays identifiable.
  Build-3119 predicted positive turning remains included.
- The fixed +/-2-degree pipe and +/-45-degree motor envelopes, 3.0 rad/s
  motor slew, Kp/Kd 4.0/2.5, +/-50 mm targets, 5000/15000/1000 ms timing,
  every breakaway parameter, the 1.2-degree friction floor and all immediate
  STOP/link/vision/motor/TI safety cutoffs are unchanged.
- Full clean Debug/Release/Vehicle/DelayTest verification passed. Text/data/
  BSS are respectively 108724/716/13780, 68212/712/13776,
  67884/712/13776 and 111316/716/13844 bytes. The user subsequently
  hardware-confirmed Step A as correct and authorized Step B+C; no
  quantitative build-3120 CSV was supplied in this handoff.

## 2026-07-31 Q2 delay-projected positive turn

- `run_1848.csv` contains five valid build-3118 Q2 attempts. Their positive
  peaks are +79.5, +75.5, +63.2, +59.1 and +68.1 mm: median +68.1 mm and
  maximum +79.5 mm. The first logged -50 mm target samples occur only once
  raw position is already +56.0..+59.1 mm, and the ball continues positive
  for another 102..357 ms before each peak. Removing the settle gate worked,
  but a raw-position-only decision is still one response horizon too late.
- Vehicle build `2026073119` passes the existing bounded delay-projected
  position into the waypoint decision. Q2 begins the existing return when
  either predicted position reaches +50 mm or raw position has actually
  crossed +50 mm. The latter remains an unconditional fallback if velocity
  is low, negative or noisy.
- This uses the already measured/default 125 ms full-loop delay and its
  existing 250 ms upper validity bound; it does not add a second delay term.
  Positive drive/braking schedules, the +1.5-degree/250 ms return pulse,
  subsequent +0.8-degree drive cap, full -2.0-degree braking, final settle,
  all actuator envelopes and every immediate safety cutoff are unchanged.
- Full clean Debug/Release/Vehicle/DelayTest verification passed. Text/data/
  BSS are respectively 108716/716/13780, 68140/712/13776,
  67844/712/13776 and 111308/716/13844 bytes. This is compile/static evidence
  only; build `2026073119` has not yet been flashed or hardware-tested.

## 2026-07-31 Q2 immediate positive-waypoint return

- `run_936.csv` contains eight build-3117 Q2 attempts. Excluding the first
  severe pass-through, the remaining seven reverse at a median raw position
  of +59.2 mm and then reach a median positive peak of +72.7 mm
  (range +59.0..+84.7 mm), about 239 ms after the logged target switch.
  Their five-second median is -49.8 mm and six of seven are inside the
  printed final +/-10 mm band, so the return schedule is broadly usable.
- The first attempt is diagnostically important rather than discardable:
  the ball reaches +125 mm while the target remains +50 mm, and the target
  does not switch to -50 mm until about 12.1 s. The existing +/-7 mm,
  <=100 mm/s and 60 ms intermediate settle gate can therefore be crossed too
  quickly without triggering, despite the printed task requiring immediate
  return rather than stability at +50 mm.
- Vehicle build `2026073118` switches from +50 mm to -50 mm on the first
  valid raw-position sample at or beyond +50 mm. The intermediate velocity
  and dwell conditions have been removed. Positive-leg braking release at
  +30 mm, low-speed -2.0-degree anti-stall behavior, the +1.5-degree/250 ms
  return pulse, subsequent +0.8-degree negative drive cap, full -2.0-degree
  braking, final settle gate, timing windows and all safety cutoffs are
  unchanged.
- Full clean Debug/Release/Vehicle/DelayTest verification passed. Text/data/
  BSS are respectively 108700/716/13780, 68116/712/13776,
  67820/712/13776 and 111292/716/13844 bytes. Build `2026073118` was hardware
  tested in the five Q2 attempts in `run_1848.csv`; its remaining
  response-horizon positive overshoot motivated build 3119.

## 2026-07-31 Q2 earlier positive brake / bounded negative launch

- Build-3116 hardware logs confirm that the stronger positive-leg schedule
  removed the previously repeatable +20..+30 mm stalls, but also identify
  excess energy. `run_277.csv` reaches a +77.8 mm positive peak, reverses
  around 3.70 s and reaches -80.3 mm; `run_364.csv` reverses around 1.20 s
  but still reaches -78.6 mm. Their largest measured negative speeds are
  approximately 289 and 273 mm/s. In both logs the +1.5-degree transition
  pulse persists briefly after measured velocity has already become negative,
  so the velocity-sign-only +1.0-degree cap starts too late.
- Vehicle build `2026073117` restores normal positive-leg braking after raw
  position reaches +30 mm instead of +35 mm. The low-speed fixed -2.0-degree
  anti-stall request and separately detected -2.0-degree/400 ms breakaway
  pulses remain, so a real early stall still receives full fixed authority.
- The +50 mm transition now receives one +1.5-degree launch pulse for 250 ms
  instead of 400 ms. When that pulse ends, every further drive-sign positive
  pipe request is capped at +0.8 degree without waiting for the delayed
  velocity estimate to become negative. Negative-pipe braking retains the
  full fixed -2.0-degree authority. Targets, gains, 125 ms prediction,
  waypoint/final gates, 5000 ms checkpoint, 15000 ms timeout, actuator
  envelopes and all immediate safety cutoffs are unchanged.
- Full clean Debug/Release/Vehicle/DelayTest verification passed. Text/data/
  BSS are respectively 108676/716/13780, 68100/712/13776,
  67796/712/13776 and 111268/716/13844 bytes. Build `2026073117` was hardware
  tested in the eight Q2 attempts in `run_936.csv`; its excessive positive
  peaks and one missed fast waypoint crossing motivated build 3118.

## 2026-07-31 Q2 asymmetric positive push / negative drive cap

- The user reports seven build-3115 trials with three positive-leg
  hesitations. Five supplied logs independently show the same split:
  `run_1472.csv` never reverses and remains near +25.1..+27.7 mm through the
  15-second timeout after two -1.5-degree pulses; `run_1583.csv` likewise
  remains near +17.6..+21.5 mm after two pulses. `run_1440.csv`,
  `run_1513.csv` and `run_1547.csv` do reverse near +45.6..+47.9 mm, but
  their negative troughs repeat at -72.0, -76.4 and -71.4 mm. At five
  seconds the three successful runs are inside the printed final +/-10 mm
  band, so the problem is excess return energy rather than wrong sign or
  invalid vision.
- Vehicle build `2026073116` separates the two legs. On the positive leg,
  raw position below +35 mm keeps at least -0.6 degree forward tilt so the
  delay-compensated velocity term cannot brake the ball to rest at +20..+30
  mm. Whenever positive-leg speed is at most 30 mm/s and the raw target is
  still outside the existing 7 mm waypoint band, the request becomes the
  fixed -2.0-degree envelope. Separately detected positive stall pulses also
  use -2.0 degrees/400 ms, still at most twice.
- On the negative leg, once measured velocity is actually toward -50 mm,
  positive-pipe drive is capped at +1.0 degree. Negative-pipe braking keeps
  the full fixed -2.0-degree authority, including after final capture.
  Global Kp/Kd, 125 ms prediction, +35 mm braking release, +/-7 mm waypoint
  band, 60 ms turn gate, 1000 ms final settle, 5000 ms earliest completion,
  15000 ms hard timeout, 2-degree pipe/45-degree motor envelopes and every
  STOP/link/vision/motor/TI cutoff are unchanged.
- Full clean Debug/Release/Vehicle/DelayTest verification passed. Text/data/
  BSS are respectively 108644/716/13780, 68108/712/13776,
  67804/712/13776 and 111236/716/13844 bytes. Build `2026073116` was hardware
  tested in `run_277.csv` and `run_364.csv`; its positive overshoot and late
  negative-leg drive cap motivated build 3117.

## 2026-07-31 Q2 positive-leg second detected breakaway

- Four build-3114 logs isolate the reported low-probability hesitation.
  `run_368.csv` never reaches +40 mm: after one -1.5-degree/400 ms pulse near
  +27 mm, it later remains around +35.7..+37.6 mm for over nine seconds while
  the remaining -1.2-degree floor cannot overcome the mechanism. By contrast,
  `run_161.csv` and `run_292.csv` show similar short pauses rescued by their
  one available -1.5-degree pulse; `run_61.csv` reaches the waypoint normally.
- Vehicle build `2026073115` changes only the positive-leg breakaway quota
  from one to at most two. A second pulse is not automatic: after the first
  pulse ends, a new 150 ms window with no more than 2 mm position span, while
  still outside the target band, must be detected. Each pulse remains
  -1.5 degrees for 400 ms. The negative leg remains limited to one pulse.
- All build-3114 timing behavior remains: +50 mm immediate waypoint,
  1000 ms final settle, no completion before 5000 ms and 15000 ms hard
  timeout. Protocol, global gains, static floor, capture schedule and fixed
  actuator/safety bounds are unchanged. Build `2026073115` was hardware
  tested in `run_1440.csv`, `run_1472.csv`, `run_1513.csv`,
  `run_1547.csv`, `run_1583.csv` and the user's two additional reported
  trials; the repeated stalls and return overshoot motivated build 3116.

## 2026-07-31 Q2 five-second checkpoint / 15-second safety window

- `run_11976.csv` contains one clean run that reaches the final band around
  3.03 s and then reports normal completion at 4.911 s near -48.6 mm and
  -24.1 mm/s. `state=1`, not fault-state 7, proves this cutoff was the
  existing final-settle completion path rather than the five-second fault.
  A second block in that file never switches from +50 mm and has only 80.8%
  valid samples, so it is not a valid tuning run.
- `run_12060.csv` is truncated while the controller is still active at
  2.667 s, but is already near -53.4 mm at 11.2 mm/s. It does not contain a
  five-second endpoint.
- Vehicle build `2026073114` implements the user's requested diagnostic
  timing behavior. Q2 cannot report completion before 5000 ms, so TI cannot
  remove motor torque before the printed five-second scoring checkpoint.
  If the final settle gate is not satisfied at five seconds, the same closed
  loop remains active and may complete later; the hard MC02 Q2 timeout is
  extended from 5000 to 15000 ms. The final -50 mm settle dwell is increased
  from 150 to 1000 ms for visible confirmation; the +50 mm intermediate
  waypoint remains a 60 ms immediate-turn gate.
- The printed performance requirement remains: the ball must already be
  near -50 mm by five seconds. A completion timestamp later than five
  seconds is a tuning failure, not a relaxed interpretation of the problem.
  STOP, link loss, invalid/stale vision, TI safe stop, motor faults and all
  angle/actuator bounds remain immediate. No TI or Jetson change is needed.
  Build `2026073114` was hardware-tested in `run_61.csv`, `run_161.csv`,
  `run_292.csv` and `run_368.csv`.

## 2026-07-31 Q2 latched asymmetric final capture

- `run_10475.csv` hardware-validates build `2026073112` far enough to expose
  a flaw in its symmetric final clamp. The actual Q2 interval is about
  4.99 s: +50 mm switches to -50 mm after about 1.39 s, but the ball first
  crosses -50 mm near -275 mm/s. The +/-0.8-degree clamp removes needed
  braking authority, after which position reaches roughly -91.7 mm, rebounds
  to +34.0 mm and times out near -28.4 mm while still moving.
- Vehicle build `2026073113` latches final capture the first time raw final
  error reaches 30 mm. After latching, the 1.2-degree static-friction floor
  remains disabled. A pipe request that opposes measured ball velocity keeps
  the full fixed 2-degree braking envelope; only non-braking drive is capped
  to +/-0.6 degree. Capture remains latched even if overshoot leaves the
  30 mm entry band, preventing a return to aggressive drive.
- The pipe was polished before this run and may have lower rolling/static
  friction. Build `2026073113` deliberately reduces energy input near the
  final target without reducing braking or changing far-field motion,
  protocol, K2 sequencing, delay compensation, actuator envelopes, safety
  cutoffs or the then-current five-second deadline. Build `2026073113` was
  hardware-tested in `run_11976.csv` and `run_12060.csv`.

## 2026-07-31 Q2 final capture zone

- Vehicle build `2026073112` implements the capture-zone change proposed
  after `run_9900.csv`. During the final Q2 -50 mm leg only, raw position
  error within 20 mm disables the 1.2-degree static-friction floor and clamps
  the final physical-pipe request to +/-0.8 degree. The clamp is applied
  after the normal PD and breakaway selection, so the final-zone bound is
  authoritative.
- Outside that final capture zone, build-3111 behavior is unchanged: Kp/Kd
  4.0/2.5, 2-degree pipe envelope, 3.0 rad/s motor slew, 1.2-degree
  near-stall floor, 1.5-degree/400 ms per-leg pulse, 60 ms intermediate
  waypoint, 125 ms compensation and the fixed five-second deadline.
- The user reports physically polishing the pipe after the previous run, so
  rolling/static friction may now be lower. This increases the relevance of
  capture-zone-only authority reduction; no global drive increase was made.
  Build `2026073112` was hardware-tested in `run_10475.csv`; the symmetric
  clamp was rejected because it also weakened high-speed braking.

## 2026-07-31 build-3111 first hardware run

- `run_9900.csv` confirms the build-3111 intermediate-waypoint change works:
  the +50 mm target switches to -50 mm after about 1.20 s instead of the
  previous 3.895 s. The positive leg reaches about +50.9 mm immediately
  before the switch, with all samples valid.
- The run still does not complete. The negative leg has about 3.79 s but
  oscillates broadly: it first passes near -47.3 mm at about -178 mm/s,
  reaches roughly -68.2 mm, returns as far as +10.0 mm, and reaches a second
  negative trough around -68.2 mm. At the five-second fault it is near
  -63.7 mm and the target is cleared. This is a final-target settling failure,
  not a waypoint timing or link failure.
- A major local mechanism is the 1.2-degree minimum static-friction drive:
  it is allowed whenever the final error is just outside the 7 mm band and
  speed is below 10 mm/s. Near the first -57.8 mm stop, only about 0.8 mm
  separates the ball from the tolerance edge, yet the full friction floor/
  saturated controller can launch the next large return. The next candidate
  change should be Q2-negative capture-zone gain/angle scheduling and should
  disable the static-friction floor close to the final target while retaining
  the current far-field and intermediate-waypoint behavior. No build beyond
  `2026073111` has been made from this observation yet.

## 2026-07-31 Q2 intermediate-waypoint timing

- `run_3803.csv` shows build-3110 does reach both Q2 targets in the correct
  order, but the +50 mm leg consumes about 3.895 s. The -50 mm leg therefore
  has only about 1.1 s before the fixed deadline and reaches about -40.5 mm
  before faulting, just 2.5 mm outside the existing -43 mm tolerance edge.
- After the timeout, requested pipe angle is zero but the now-faulted,
  torque-disabled mechanism reverses the ball from about -43.1 mm to roughly
  +120 mm. This post-fault movement is not a continued controller request;
  it is consistent with the loaded linkage/pipe falling away from level after
  the immediate safety cutoff. Do not weaken the fault cutoff to mask it.
- Vehicle build `2026073111` changes only the intermediate +50 mm settle
  gate. It retains the existing +/-7 mm position band but permits up to
  100 mm/s and needs 60 ms dwell before switching to -50 mm. The final
  -50 mm completion remains limited to 60 mm/s and 150 ms dwell.
- Kp/Kd 4.0/2.5, 3.0 rad/s motor slew, 1.2-degree low-speed friction floor,
  1.5-degree/400 ms delayed per-leg breakaway, 125 ms compensation, fixed
  2-degree pipe/45-degree motor envelopes, five-second deadline and all
  safety cutoffs are unchanged. Build `2026073111` is not hardware-validated.

## 2026-07-31 Q2 overshoot rebalance

- `run_3417.csv` captures build-3109's first full aggressive-Q2 trial. The
  +50 mm target is first crossed about 1.02 s after it is asserted at
  +50.74 mm and roughly +129.5 mm/s. Positive braking is not requested until
  about 1.10 s at +61.49 mm, and the measured position peaks at +133.63 mm.
  The ball then oscillates across the target without meeting the velocity/
  settle gate; the target never changes to -50 mm before the fixed deadline.
- Vehicle build `2026073110` retains the 1.2-degree directional
  static-friction floor, 2-degree fixed pipe envelope, 3.0 rad/s motor slew,
  150 ms target settle and 125 ms delay compensation. It rebalances Kp/Kd
  from 5.0/1.2 to 4.0/2.5 so velocity braking starts earlier.
- The floor now applies only below 10 mm/s instead of 30 mm/s. The per-leg
  stall pulse is reduced from 2.0 degrees/650 ms to 1.5 degrees/400 ms, and
  first-leg stall declaration moves from 300+120 ms to 650+150 ms. This
  preserves a decisive recovery for a genuinely stuck ball without declaring
  the normal actuator/linkage delay to be a stall.
- `VehicleCommissioningAggressiveQ2` now writes the same live Kp=4.0,
  Kd=2.5, max-pipe=2.0 degrees, slew=3.0 rad/s and delay=125 ms values.
  Build `2026073110` is not hardware-validated yet.

## 2026-07-31 aggressive Q2 static-friction drive

- Vehicle build `2026073109` responds to the hardware observation that the
  ball stopped near +32 mm while the DM4310 continued to move back and forth.
  The supplied `run_2279.csv` does not contain that K2 interval: all 1,314
  rows have question/target/command equal to zero over 35.49 s, so the
  observation is supported by the user's direct report and the separate
  100 Hz Ozone summary, not by that CSV.
- Q2 now applies a bounded directional minimum drive whenever the raw target
  error remains outside the existing 7 mm tolerance and absolute estimated
  velocity is at most 30 mm/s: `-1.2 deg` toward the +50 mm target and
  `+1.2 deg` toward the -50 mm target. This is Coulomb/static-friction
  feed-forward, not an integral term, so it cannot wind up and reverses only
  with the target sign.
- The per-leg breakaway pulse is now the existing fixed pipe envelope
  (`2.0 deg`) for 650 ms. First-leg stall detection arms after 300 ms and
  requires a 120 ms / 2 mm stable window. Kp/Kd defaults are 5.0/1.2, motor
  slew/v_des is 3.0 rad/s, and target settle is 150 ms. Fixed 2-degree pipe,
  45-degree motor and five-second Q2 bounds, stale/invalid vision handling,
  STOP, TI/Jetson/motor fault cutoffs and 125 ms compensation are unchanged.
- `VehicleCommissioningAggressiveQ2` writes the same 2.0-degree, Kp=5.0,
  Kd=1.2, 3.0 rad/s and 125 ms values live after a reset. Existing older
  commissioning helpers remain for deliberate rollback.
- Clean Debug/Release/Vehicle/DelayTest verification passed. Text/data/BSS
  are respectively 108,100/716/13,780, 67,716/712/13,776,
  67,420/712/13,776 and 110,700/716/13,844 bytes. This is compile/static
  verification only; build `2026073109` has not yet been flashed or tested
  on the assembled vehicle.

## 2026-07-31 Q2 per-leg stall breakaway

- Vehicle build `2026073108` replaces the build-3107 second-leg-only
  breakaway trigger with one independent, directional opportunity per Q2
  leg. On the first `+50 mm` leg, after an 800 ms response grace, a fresh
  calibrated vision window that stays within 2 mm for 250 ms while still
  more than the existing 7 mm target tolerance away starts one `-1.2 deg`
  physical-pipe pulse for 350 ms. Continuous position travel resets that
  window. The pulse cannot repeat on the same leg.
- Completing the existing +50 mm position/velocity settle gate still changes
  the target to -50 mm. That gate already proves the ball is stationary, so
  the second leg immediately starts its one `+1.2 deg / 350 ms` pulse rather
  than waiting another 250 ms. Both signs follow the frozen convention
  `x > 0` toward the motor and `alpha_pipe > 0` with the motor end high.
- Each pulse is applied only while vision remains valid. Invalid/stale vision,
  STOP, any stopped/fault state, TI safe stop and the fixed five-second Q2
  timeout clear the active pulse and stall window. The existing 0.8-degree
  live PD clamp, Kp=3, Kd=2.0 commissioning value, 125 ms compensation,
  1.2 rad/s motor slew, fixed 2-degree pipe/45-degree motor envelopes,
  protocol and all non-Q2 behavior are unchanged.
- Ozone adds `q2_breakaway_used_this_leg`, `q2_stall_elapsed_ms` and
  `q2_stall_span_um`. `q2_breakaway_pipe_angle_mdeg` is now the signed last
  pulse (`-1200` first leg or `+1200` second leg), and the count can reach at
  most two in one Q2 run.
- The 100 Hz Data Sampling capture preceding this change showed the Q2 target
  reached `+50000` but never `-50000`, while `q2_breakaway_count` and
  `q2_breakaway_active` remained zero. Commanded and feedback motor positions
  tracked closely and the observed feedback velocity reached about
  0.945 rad/s. This is evidence that the old target-transition-only trigger
  was never reached on that attempt; it is not hardware validation of the new
  build.
- Clean Debug/Release/Vehicle/DelayTest verification passed. Text/data/BSS
  are respectively 107,948/716/13,780, 67,620/712/13,776,
  67,308/712/13,776 and 110,548/716/13,844 bytes. This is compile/static
  verification only. Build `2026073108` has not yet been flashed or tested on
  the assembled vehicle.

## 2026-07-31 Q2 second-leg breakaway pulse

- Vehicle build `2026073107` implements the previously proposed Q2-only
  breakaway experiment. When the raw position/velocity settle gate completes
  the +50 mm leg and changes the target to -50 mm, MC02 requests one
  `+1.2 deg` physical pipe pulse for 350 ms, then automatically resumes the
  existing delay-compensated PD controller and its live
  `max_pipe_angle_deg` clamp (currently commissioned at 0.8 degree).
- The pulse does not run at question start and cannot retrigger within the
  same target transition. It is applied only while the current vision sample
  passes the existing calibrated/fresh/confidence gate. Invalid vision
  requests level as before. STOP, any stopped/fault state, question restart,
  TI safe stop and the unchanged five-second Q2 timeout clear the pulse
  deadline.
- Existing Kp=3, Kd=2.0 live commissioning value, measured 125 ms delay
  compensation, 1.2 rad/s motor slew, 45-degree motor limit, targets and
  protocol payloads are unchanged. The pulse maps to about 27.3 motor degrees
  through the installed 0.044 ratio and remains below the existing
  45-degree motor envelope.
- Ozone aggregate debug now exposes `q2_breakaway_active`,
  `q2_breakaway_remaining_ms`, `q2_breakaway_count` and
  `q2_breakaway_pipe_angle_mdeg`; `command_pipe_angle_mdeg` should show
  approximately 1200 during the pulse and return to the normal controller
  output afterward.
- Clean Debug/Release/Vehicle/DelayTest verification passed. Text/data/BSS
  are respectively 107,260/716/13,740, 67,148/712/13,736,
  66,836/712/13,736 and 109,860/716/13,804 bytes. This was compile/static
  verification. A later 100 Hz Ozone capture showed the transition-only
  trigger was not reached during the observed first-leg failure; see the
  build-3108 section above.

## 2026-07-31 first compensated Q2 hardware attempt

- The first stationary K2 run with Vehicle build `2026073105`,
  `control_total_delay_ms=125` and `max_pipe_angle_deg=0.5` moved the ball in
  the intended positive direction but stopped near +35 mm rather than reaching
  +50 mm. The motor then returned to level and the retained MC02 state was
  `state=6`, `fault=6`, `competition_phase=8`. At the post-stop capture the
  Jetson and TI links were both online: vision age 21 ms, processing latency
  13.04 ms, flags 15, Jetson heartbeat age 64 ms, TI online/state/fault
  1/0/0 and zero TI CRC errors. This is hardware evidence only for that one
  bounded attempt.
- Source tracing found a diagnostic-fault overwrite. The Q2 application has a
  five-second `GIMBAL_Q2_TIMEOUT_MS`; if it first raises
  `GIMBAL_FAULT_BAD_COMMAND=5`, `ti_link_poll()` observes the gimbal fault and
  calls `force_stop(now_ms, 1)`, whose subsequent
  `gimbal_app_force_ti_safe_stop()` overwrites the retained cause with
  `GIMBAL_FAULT_TI_LINK=6`. Thus retained fault 6 does not prove an actual TI
  dropout in this capture.
- Build `2026073106` fixes only that overwrite. TI supervisor stops now carry
  one of three explicit modes: normal stop, real TI-link fault, or preserve
  the already-latched gimbal fault. A Q2 deadline failure therefore remains
  `GIMBAL_FAULT_BAD_COMMAND=5`; genuine missing/faulted TI status still becomes
  `GIMBAL_FAULT_TI_LINK=6`. The user explicitly confirmed that the printed Q2
  total time is five seconds, so `GIMBAL_Q2_TIMEOUT_MS` remains exactly
  5000 ms and the verifier locks it. No controller gain, 0.5-degree live
  commissioning setting, target, delay compensation, protocol, or TI firmware
  changed.
- Clean Debug/Release/Vehicle/DelayTest verification passed. Text/data/BSS are
  respectively 106,988/716/13,716, 66,932/712/13,712,
  66,636/712/13,712 and 109,588/716/13,780 bytes. Vehicle retains Ozone DWARF
  aggregate types. Build 2026073106 has not yet been flashed or hardware
  tested.
- The subsequent 2026073106 K2 attempt reached/crossed the +50 mm target and
  reversed correctly toward -50 mm, but the fixed five-second competition
  deadline expired near -20 mm. This establishes that target switching,
  physical sign and the bounded compensated controller operated in the
  intended order in that attempt; it does not yet establish scored completion.
  Keep Kp=3, Kd=2.5, total delay=125 ms and the five-second deadline fixed for
  the next single-variable trial. `gimbal_MC02_Vehicle.jdebug` now provides
  `VehicleCommissioning08`, which writes only max pipe angle 0.8 degrees and
  restores delay 125 ms. This Ozone helper does not change the firmware image
  or build ID.
- In the 0.8-degree follow-up, the user reports that the first leg reversed
  near +30 to +39 mm before visibly completing +50 mm; response and reversal
  were slow, and the five-second stop occurred near +30 mm. Do not increase
  angle again from this observation. With Kp=3 and a roughly 140 ms live
  prediction horizon, position projection contributes about 0.42 seconds of
  additional effective velocity feedback, making the current Kd=2.5 behave
  near 2.9. The next bounded single-variable trial is max pipe 0.8 degrees,
  Kp=3, Kd=2.0 and delay=125 ms. The Ozone-only helper
  `VehicleCommissioning08Kd20` writes exactly those live values; firmware,
  build ID and the five-second deadline remain unchanged.
- `run_4343.csv` captures the subsequent Kp=3, Kd=2.0,
  max-pipe=0.8-degree, delay=125 ms attempt. The active +50 mm target lasted
  4.936 s and never switched to -50 mm before the fixed timeout. The CSV has
  only 97 active samples, 19.65 Hz with 51.64 ms median spacing, despite the
  separate report that vision had been restored to about 50 FPS. All 97
  samples are marked valid.
- This capture does not support the interpretation that MC02 requested
  conservative motion: 59/97 active samples (60.8%) report at least
  0.75 degree absolute requested pipe angle, and the requested value reaches
  both -0.8 and +0.8 degrees. The reported vision estimate ranges from
  -4.84 mm to +79.67 mm and makes two large apparent excursions about the
  +50 mm target. It never remains within the existing position/velocity
  settle gate for 250 ms, so Q2 stays on its positive leg.
- The user simultaneously reports that the physical ball barely moved. This
  conflicts materially with the CSV estimate and must be resolved before
  increasing angle, gain or slew. The V3 `command_angle_mdeg` field is
  `s_command_pipe_angle_mdeg`, the controller's requested pipe tilt before
  motor slew and motor feedback; the CSV therefore cannot establish actual
  actuator following. The next safe test is recording-off/CSV-only at the
  claimed 50 FPS while Ozone observes `requested_position_rad`,
  `command_position_rad` and `feedback_position_rad`, plus a held-ball check
  that pipe motion does not create several centimetres of false visual
  position change. The current 1.2 rad/s motor slew means a 0.8-degree pipe
  command maps through the 0.044 ratio to about 18.2 motor degrees and takes
  about 0.265 s from neutral or 0.529 s for a full reversal; raise it only
  after the vision/physical discrepancy is excluded.
- The recording-off repeat `run_5167.csv` plus the user's 30 FPS phone video
  resolves that discrepancy. The active Q2 interval contains 269/269 valid
  rows at 53.85 Hz (19.10 ms median spacing); processing latency is 18.91 ms
  median. The phone video independently shows the same qualitative ball
  motion, so the calibrated vision position is not inventing the large first
  excursion.
- The +50 mm leg now succeeds: it lasts about 1.80 s, peaks at +51.10 mm and
  switches to the -50 mm leg. During the entire remaining 3.173 s negative
  leg, every recorded controller request is exactly +0.8 degree, yet position
  remains in +45.94 to +49.09 mm with median +46.70 mm and median velocity
  approximately -0.25 mm/s. The video likewise shows only a small return
  motion followed by a stop. Q2 therefore times out because the ball cannot
  restart toward -50 mm, not because of Jetson frame rate, invalid samples,
  target switching, Kp/Kd cancellation or insufficient requested command.
- The same +0.8-degree request was already used to decelerate the moving ball
  before the +50 mm settle/switch, so its sign and at least some physical
  braking effect are established. The leading, but not yet directly measured,
  explanation is breakaway/static friction or a local tube trap: the bounded
  +0.8-degree tilt can stop a moving ball but cannot restart it once stationary.
  Do not raise Kp/Kd. The most targeted next controller experiment is a
  one-shot positive-pipe breakaway pulse after the Q2 target switches to
  -50 mm (+1.2 degrees for 350 ms), then return to the existing 0.8-degree
  PD clamp. Build `2026073107` now implements this bounded experiment while
  preserving first-leg tuning and the fixed five-second deadline; hardware
  behavior remains unverified. An actual motor-feedback latch would
  distinguish static friction from a failed reverse motor-following command
  if needed.

## 2026-07-31 Vehicle full-loop-delay compensation

- The user completed the dedicated total-loop-delay experiment at about
  49 FPS: 24 edges were found, nine starting edges were accepted, median
  delay was 125 ms, mean 128 ms and reported dispersion 32 ms. This is
  hardware evidence for the current assembled visual/motor/linkage loop, but
  the dispersion means 125 ms is an initial compensation value rather than a
  precision constant.
- MC02 build `2026073105` consumes that result in the competition Vehicle
  controller. Before the existing PD calculation it projects position with
  bounded constant velocity:
  `x_pred = clamp(x + v * (125 ms + receive_age), +/-130 mm)`.
  The total horizon is capped at 250 ms. The original raw position remains
  authoritative for target-settle decisions, and invalid/stale vision still
  requests zero tilt. The existing +/-2 degree pipe limit, 45-degree motor
  offset limit, 1.2 rad/s slew limit and all watchdog/fault cutoffs are
  unchanged.
- The frozen V3 32-byte VISION_SAMPLE wire layout is unchanged. MC02 now
  decodes its already-existing byte-8 `processing_latency_us` field for Ozone
  diagnostics; it is not added separately because the measured full-loop
  delay already contains Jetson processing and USB return latency.
  `g_gimbal_debug` exposes `control_total_delay_ms` (default 125),
  `control_prediction_horizon_ms`, `control_predicted_position_um`,
  `control_velocity_um_s` and `vision_processing_latency_us`. Writing delay
  zero disables projection for a deliberate A/B check; values above 250 fall
  back to 125.
- Full offline verification passed for clean Debug, Release, Vehicle and
  DelayTest builds. Their text/data/BSS sizes are respectively
  106,972/716/13,716, 66,908/712/13,712,
  66,612/712/13,712 and 109,564/716/13,780 bytes.
  `gimbal_MC02_Vehicle.jdebug` is bound explicitly to
  `build/Vehicle/gimbal_MC02.elf` so Ozone cannot accidentally reflash the
  DelayTest image. Build 2026073105 has not yet been flashed; compensated Q2
  behavior remains hardware-unverified. First powered run must start with the
  existing `max_pipe_angle_deg=0.5` commissioning limit and K2/stationary
  chassis.
- Ozone initially displayed `g_gimbal_debug` only as one address and rejected
  `.build_id` as `<tofscope>`. The cause was Vehicle's inherited
  `Release=-Os -g0`, which removed the `GimbalDebug` DWARF type while retaining
  the global address. The Vehicle preset now enables `GIMBAL_OZONE_WATCH` and
  appends `-g3` after `-g0`; optimization and executable behavior remain
  `-Os`, while Ozone can expand the structure. Debug, Release and DelayTest
  preset semantics are unchanged.

## 2026-07-31 DelayTest position-stability admission

- MC02 build `2026073104` fixes a real first-measurement admission mismatch.
  With the field manual's temporary `r_meas_cm=0.001`, a physically stationary
  ball at -0.432 mm was reported by the Jetson Kalman state as -102.7 mm/s;
  the old instantaneous `|v| <= 20 mm/s` gate therefore denied request 4.
  The observed V3 position, age, required flags, Jetson online/ready state and
  heartbeat age were otherwise valid.
- DelayTest measurement admission now requires the ball to remain inside
  +/-10 mm, at least eight valid samples, and no more than 2 mm position span
  over a continuous 300 ms window. Invalid/occluded/out-of-range samples,
  confidence below 300, leaving the center band, or a sample gap above 100 ms
  reset the window. The window resets after every pulse, so all 8-10 trials
  require a fresh stationary hold. Ozone exposes stable-ready, elapsed time,
  span and sample count.
- The frozen Jetson V3 wire format and normal competition controller are
  unchanged. The five-minute global OUT1 guard and all immediate stop/fault/
  link-watchdog cutoffs remain in force. Full offline verification passed:
  Debug, Release, Vehicle and DelayTest use 107,316/14,400,
  67,440/14,384, 67,160/14,384 and 109,916/14,456 bytes of
  FLASH/DTCMRAM respectively. This does not prove the new admission behavior
  on hardware.

## 2026-07-31 five-minute global OUT1 guard

- MC02 build `2026073103` extends the shared guarded OUT1 power deadline
  from 180 seconds to 300 seconds for the two-operator total-loop-delay
  measurement workflow. The DelayTest accepted-request renewals continue to
  renew this same deadline, now to five minutes.
- This changes the global bench-power guard, so it also applies to the
  ordinary PWRON/CALRUN/JOG commissioning paths. STOP, PWROFF, reset, K7/K8,
  TI safe stop, feedback/CAN/motor/Jetson/vision faults and link watchdogs
  retain their existing immediate cutoff behavior.
- Full offline verification passed for Debug, Release, Vehicle and DelayTest.
  FLASH/DTCMRAM use is respectively 107,316/14,384 bytes,
  67,440/14,368 bytes, 67,152/14,368 bytes and 109,324/14,416 bytes.
  This is not evidence that the new five-minute timeout has been flashed or
  physically timed on hardware.

## 2026-07-31 DelayTest operator-attention timeout renewal

- MC02 build `2026073102` fixes a live-test workflow defect found during the
  first empty-mechanism run. Build 2026073101's single 180-second OUT1
  deadline continued counting while the operator inspected the empty pulse,
  so a correct phase-3/6/7 wait could end in phase 8 / fault 3 before the
  8-10 measurement repetitions finished.
- Each accepted DelayTest empty-validation, mechanical-acknowledgement or
  measurement request now renews the existing bounded 180-second deadline.
  An invalid/denied request does not renew it. STOP, K7/K8/TI safe stop,
  feedback/CAN/motor/Jetson/vision faults, reset and an unattended 180-second
  interval still disable torque and remove OUT1 power.
- The first physical empty pulse on 2026073101 completed and returned within
  about 0.00038 rad of the captured motor zero, with phase 6, pulse_count 1
  and fault 0 visible in Ozone. This is operator evidence for that one empty
  pulse only, not a full delay measurement or general mechanical validation.

## 2026-07-31 dedicated total-loop-delay firmware

- MC02 build `2026073101` adds a separate `DelayTest` CMake preset for the
  `total_delay_ms` experiment in the field measurement manual. The normal
  Debug/Release/Vehicle presets compile `GIMBAL_ENABLE_DELAY_TEST=0`;
  DelayTest alone compiles it as one and also removes manual CALRUN.
- The only test waveform is pipe `0 -> -1.5 deg` for 500 ms then zero,
  using the measured 0.044 pipe/motor ratio and a fixed 12 rad/s DM4310
  position-speed command. There is no arbitrary angle or repeating-wave
  entry. The identical pulse must complete once without a ball and then
  receive a separate Ozone mechanical acknowledgement before any
  ball-present pulse is accepted.
- Every non-STOP delay request needs the independent
  `0xD31A7E57` three-second key. A measurement additionally requires Jetson
  online/ready, a fresh calibrated vision sample, valid velocity,
  `|x| <= 10 mm` and `|v| <= 20 mm/s`. Feedback, motor, CAN, return,
  Jetson/vision and existing TI/STOP cutoffs remain active; stop/fault/reset
  clears the empty-pulse acknowledgement.
- Only DelayTest raises the unchanged V3 `0x81 GIMBAL_STATUS` payload to
  100 Hz. No V3 frame, message ID, payload length, field, unit, sign or CRC
  changed. See `docs/DELAY_TEST_FIRMWARE.md` for the Ozone request/phase
  sequence. This source/build work does not claim powered-motion validation
  or a measured delay.
- `gimbal_MC02_DelayTest.jdebug` opens the DelayTest ELF explicitly. The
  original `gimbal_MC02.jdebug` intentionally remains bound to the ordinary
  Debug ELF, which otherwise overwrites a separately flashed DelayTest image
  whenever Ozone downloads from that project.
- Ozone freezes symbol-window editing while the CPU runs, and project-script
  functions are invoked from Console through `Script.Exec`, not by typing
  their bare names. The DelayTest project provides atomic key/request
  helpers backed by `Target.WriteU32`: `Script.Exec("DelayTestPrepare")`,
  `Script.Exec("DelayTestValidateEmpty")`,
  `Script.Exec("DelayTestAckMechanical")`,
  `Script.Exec("DelayTestMeasure")` and `Script.Exec("DelayTestStop")`.
  They do not halt the control loop; never halt the CPU to post a powered
  test request.

## 2026-07-30 visual-integration conversation handoff

- Added `../视觉联调交接.md` as the self-contained entry point for the new
  visual-integration conversation. It captures live build IDs, TI/MC02/
  Jetson ownership, V2/V3 links, five-question/K6 behavior, connections,
  calibration blockers, unverified hardware claims and a staged test order.
- Synchronized `docs/FIVE_QUESTION_CONTROL.md` to MC02 `2026073013` / TI
  `2026073012`, the three-second start countdown and K6 software-power
  permission. Updated only the implementation-build reference in the frozen
  V3 document; no V3 frame, message, field, unit, sign or CRC changed.
- The handoff flags that parts of `../competition/competition` documentation
  retain obsolete protocol/architecture text. New work must treat
  `docs/JETSON_MC02_PROTOCOL_V3.md` and live source as authoritative. This
  handoff update made no firmware change and did not repeat hardware tests.
- The handoff was then expanded with the explicit scope boundary requested
  by the user (no TI route/control changes), the V3 event-to-recording
  mapping, Q2's event-5 completion marker, five-point and independent-point
  calibration procedure, MC02 Ozone variables, live controller tunables,
  production ELF path and the exact evidence the new conversation should
  request. This remained documentation-only.

## 2026-07-30 K6 chassis software-power permission

- MC02 build `2026073013` is paired with TI build `2026073012`. K6 is no
  longer behaviorally unused: its existing frozen V2 `0xA2 BUTTON_EVENT`
  toggles a mirrored chassis software-power permission while the supervisor
  is idle. No V2 frame, message/action number, field/length, CRC, option bit,
  button ID or question ID changed, and the frozen protocol document was
  not edited.
- Both controllers default the permission to zero. Motion questions
  K1/K3/K4/K5 are accepted only after K6 has set permission one. K2 is still
  accepted with permission zero and explicitly clears it because the
  chassis must remain stationary. K6-off during a sequence commands
  SAFE_STOP; route-completion SAFE_STOP, K7, K8, faults and link loss also
  clear the mirrored latch. TI remains the final motor-authority gate if a
  button event is ever lost.
- TI OLED displays `PWR 0/1`, which means software permission rather than
  measured physical 12 V. The V2 `MOTOR_OUTPUT_ENABLED` flag still means
  actual TI motor-arm state and was not redefined.
- Full MC02 offline verification passed: Debug FLASH/DTCMRAM is
  107,188/14,320 bytes, Release is 67,352/14,312 and Vehicle is
  67,072/14,312. Paired TI verification also passed at Debug text/BSS
  30,984/2,496 and Release 20,888/2,281 bytes. Neither image was flashed in
  this work session; K6 synchronization and safe cutoff remain
  hardware-unverified. No gimbal/ball-control constant or algorithm changed.

## 2026-07-30 Jetson five-point calibration handoff

- The Jetson owner reports that the geometric pipe center is visually
  correct while the displayed +/-5 cm and +/-1 cm marks are displaced.
  This confirms the current pixel-to-metric polynomial is only a guide and
  is not a usable calibration. Jetson now keeps `fitted=false` and
  `sign_verified=false`, so it does not set V3 `CALIBRATED`.
- The proposed physical calibration records ball-center samples at
  +10, +5, 0, -5 and -10 cm, fits a quadratic for five samples, checks
  monotonicity and residuals, and deliberately leaves `sign_verified=false`
  until a person confirms that the motor end produces positive x. No
  measured pixels, fitted coefficients or physical error figures exist yet.
- MC02 behavior is compatible and unchanged. `vision_sample_valid()` needs
  `BALL_VALID | PIPE_VALID | CALIBRATED`, a fresh sample and confidence at
  least 300; therefore leaving `PIPE_VALID` and `CALIBRATED` set on a frame
  with `BALL_VALID` clear cannot authorize closed-loop control. Before
  enabling competition control, also validate the fitted map at independent
  non-fit points (for example +/-2.5, +/-7.5 and the accessible near-end
  positions) so residuals at the five fitted points are not mistaken for
  full-range accuracy required by internal Q5.

## 2026-07-30 USART1 connector pin-order correction

- The user supplied the DM-MC-Board02 V1.1 USART1 connector figure and
  correctly identified that the middle contact, pin 2, is RX/PA10. The
  keyed/front-view order is now recorded consistently as pin 1 PA9/TX,
  pin 2 PA10/RX and pin 3 GND. Earlier tables that called pin 2 TX, pin 3
  RX and pin 1 GND were wrong and have been corrected in the MC02 wiring
  checklist, the V2 communication document and the TI-side wiring copy.
- Firmware direction was already correct and did not require a functional
  change: `gimbal_MC02.ioc` maps `PA9.Signal=USART1_TX` and
  `PA10.Signal=USART1_RX`; `ti_link.c` initializes PA9/PA10 as USART1 AF7
  and uses USART1 in TX/RX mode at 115200 8N1. The offline verifier now
  asserts both MCU signal mappings and all three connector-table entries so
  this documentation reversal cannot silently recur. No TI control or route
  source was changed.

## 2026-07-30 full five-question final verification

- Re-read both live agent logs after the concurrent chassis completion and
  preserved the newer paired baseline: MC02 `2026073012`, TI
  `2026073011`. The MC02 verification script and the README, Jetson V3,
  TI V2 and five-question control documents were synchronized to those
  exact build IDs; no frozen wire field, message number, payload length,
  CRC or sign convention changed.
- `tools/verify_project.ps1` then completed clean Debug, Release and Vehicle
  builds and all structural/CRC checks. FLASH/DTCMRAM use is
  107,044/14,320 bytes (Debug), 67,224/14,304 (Release) and
  66,944/14,304 (Vehicle). The Vehicle compile database confirms manual
  CALRUN is absent while Jetson V3, TI V2 and all five competition paths
  remain linked.
- This is the complete source/build baseline requested by the user, rather
  than the older K1-only restricted baseline. It is ready to flash for
  commissioning. Powered end-to-end behavior and controller gains remain
  physical test/calibration results, not facts established by compilation.

## 2026-07-30 five-question chassis completion

- MC02 build `2026073012` is paired with TI build `2026073011`. The frozen
  V2 wire envelope, message/action numbers, payload lengths, CRC,
  option-bit meanings and question/button IDs were not changed.
- K1-K5 now all enter the common question supervisor. MC02 waits for its
  existing question-preparation readiness, sends TI PREPARE, waits for the
  matching READY acknowledgement, performs a restored three-second
  countdown, then sends idempotent START. The unlogged intermediate
  `2026073011` source had used 200 ms; that was not retained.
- For Q2, TI remains continuously disarmed and does not decide when the
  ball task ends. The existing MC02 gimbal-app completion/fault query is the
  local completion indication; `ti_link.c` converts normal completion into
  the frozen V2 SAFE_STOP and converts a fault into the existing faulted
  SAFE_STOP path. TI has a 30-second stationary fail-safe ceiling, while the
  task controller may complete or fault earlier.
- Q1 retains the 120 RPM/20-second tuned lap. Q3 is TI's 1500 mm A-to-B
  route with a 100 RPM cruise, 45 RPM from 1250-1450 mm and 20 RPM over the
  final 50 mm, an 8-second ceiling and B event. Q4/Q5 reuse the one-lap route at 100 RPM with a
  30-second ceiling. MC02 sends SAFE_STOP on TI route completion. No
  ball-control constant or algorithm was changed in this chassis work.
- Clean CMake builds passed: Debug FLASH 107,044 bytes/DTCMRAM 14,320 bytes;
  Release FLASH 67,224 bytes/DTCMRAM 14,304 bytes. This is compile evidence
  only; build `2026073012`, the five button sequences, Q2 completion,
  Q3 B timing/distance and Q4/Q5 lap timing remain hardware-unverified.

## 2026-07-30 independent pre-flash rebuild

- The root agent independently reran TI `tools/verify_project.ps1` and clean
  MC02 Debug/Release CMake builds after the eight-button audit. All commands
  completed successfully. The freshly produced MC02 images retain
  `GIMBAL_BUILD_ID=2026073010`; Debug uses 99,164 bytes FLASH/13,464 bytes
  DTCMRAM and Release uses 62,436/13,448.
- This clears the software build gate only. It authorizes the first
  logic-only UART/button test with both motor power rails disconnected; it
  does not establish electrical UART operation, button wiring, stop timing,
  Jetson V3 operation or safe powered motion.
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

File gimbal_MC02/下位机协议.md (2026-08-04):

# 与 MC02 的通信 —— Jetson 侧实现说明

对应协议文档 **V3**（`version` 字节 = `0x03`）。这份写 Jetson 侧实现了什么、验证到哪一步、还差什么。

> ⚠️ MC02 build `2026073008` 的二进制解码尚未实现，且协议版本必须**双方同时切到 V3**。
> 版本对不上的现象是"链路有数据但一帧都收不到" —— 收到非 V3 帧时程序会打一次
> `[WARN] 收到 version=0x.. 的帧`，看到这条就是固件版本没跟上。

> **V3 相对 V2 只改了 version 字节**（`0x02` → `0x03`），报文布局一字节没动。
> 改版本号是为了把三条符号约定定死，让新旧固件互相收不到而不是悄悄跑出正反馈：
> ① 球位正方向 = 从中心 O 指向**电机/物理左端**（几何约定，与下坡方向无关）；
> ② `positive_end_px` 填电机/左端像素、`negative_end_px` 填铰链/右端，即使数值大小是反的；
> ③ `command_angle_mdeg` = **物理摆杆倾角**，电机端抬起为正 ⇒ 球加速度为负。
> Jetson 侧过程模型已按 ③ 改成 `ẍ = −ball_accel_gain·α`（见 `main.cpp` 的 `accel_gain`）。

---

## 0. ★ 题号有两套编号，别搞混 ★

协议内部的 `question_id` **不等于**题面的要求编号：

| `question_id` | 题面第几项 | 测试内容 |
|---:|---:|---|
| 1 | **2** | 跑一圈并停回 A |
| 2 | **3** | 车静止，球 O → +5cm → −5cm |
| 3 | **4** | 从 A 出发通过 B，球保持在 O |
| 4 | **5** | 整圈通过 A，球保持在 O |
| 5 | **6** | 整圈通过 A，球保持在指定位置 |
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

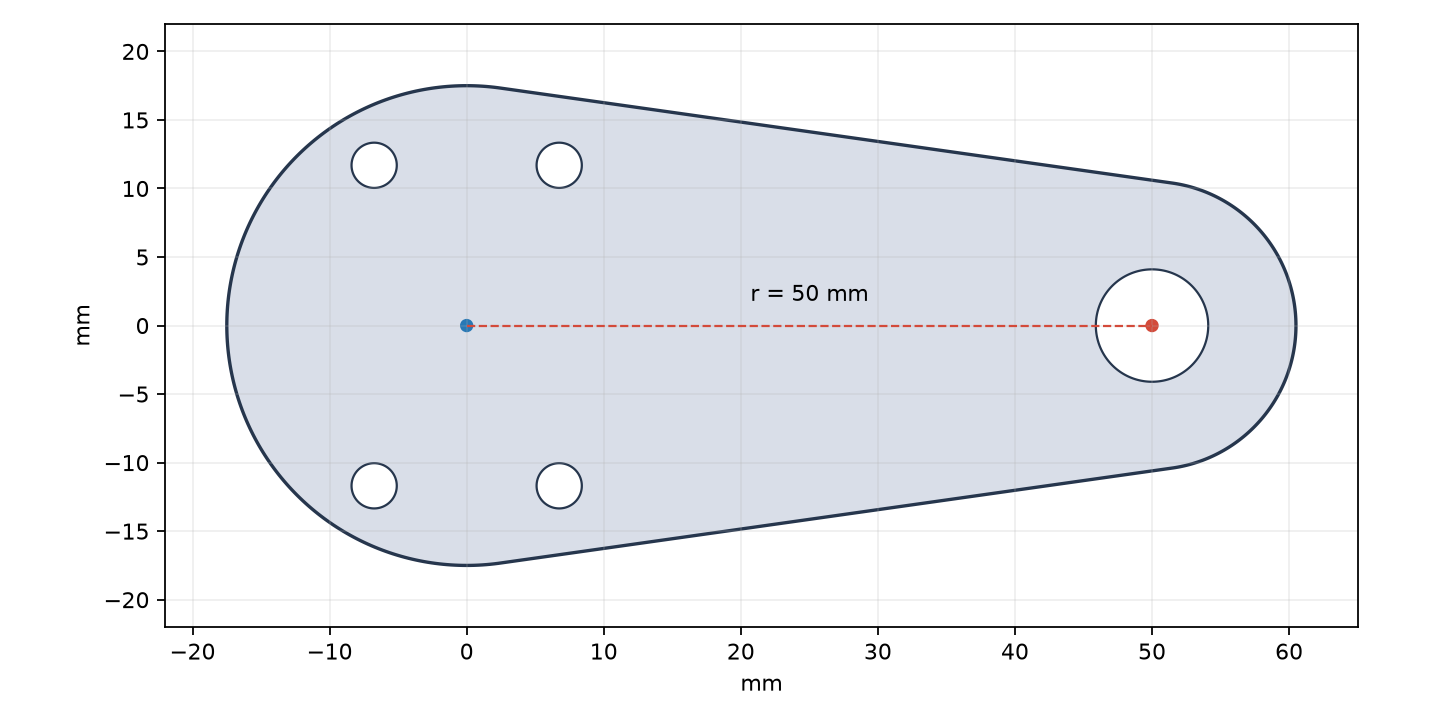
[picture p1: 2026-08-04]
gimbal_MC02/mechanical/DM4310_CRANK_R50_M8_V1_preview.png

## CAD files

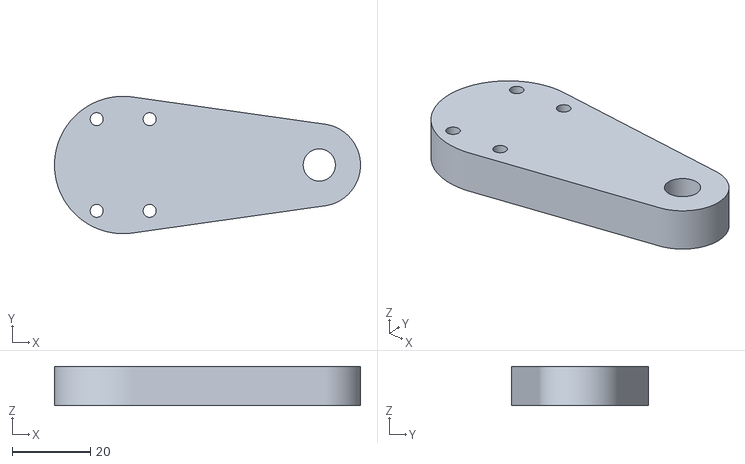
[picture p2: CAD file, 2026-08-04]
gimbal_MC02/mechanical/DM4310_CRANK_R50_M8_V1.stl
78.0 x 35.0 x 10.0

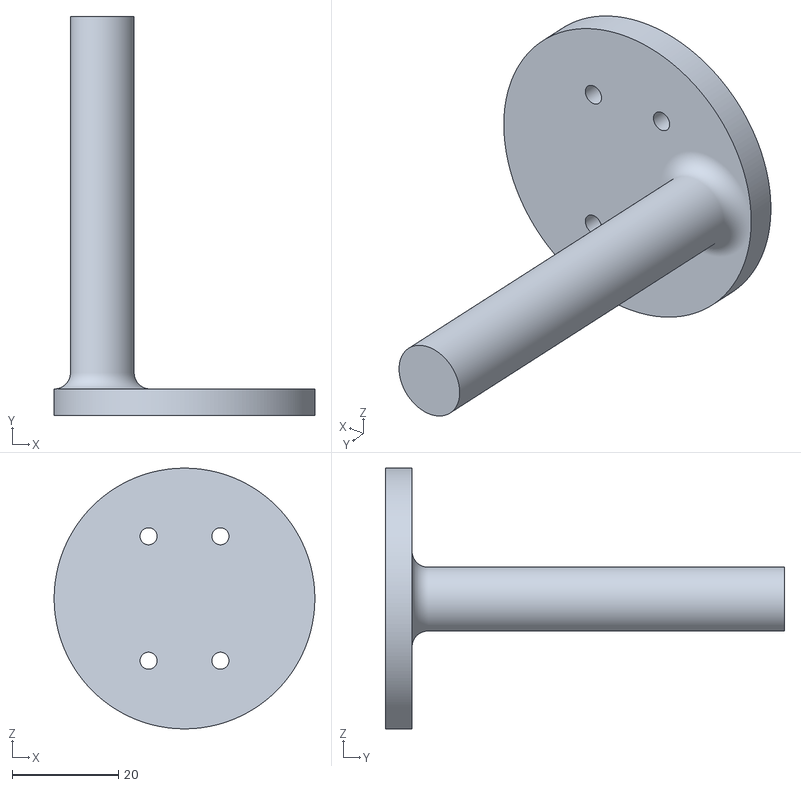
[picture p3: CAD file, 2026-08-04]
gimbal_MC02/mechanical/final/PITCH_FINAL_R15P45_R3_20260730.STL
49.0 x 75.0 x 49.0

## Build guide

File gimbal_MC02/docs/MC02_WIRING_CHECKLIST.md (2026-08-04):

# DM-MC-Board02 wiring and commissioning checklist

Applies to MC02 build `2026073106`, DM-J4310-2EC V1.2, Jetson Orin Nano,
TI LP-MSPM0G3507 and J-Link.

Source checked visually against DM-MC-Board02 V1.1 manual pages 3, 4, 6, 7,
13 and 15. Connector numbering below follows the keyed connector front views
in that manual. Always confirm the board silkscreen before inserting a cable.

## 1. Non-negotiable rules

- [ ] Disconnect the 6S battery before changing power, CAN or UART wiring.
- [ ] Keep an accessible master switch or battery connector for emergency stop.
- [ ] Add a fuse in the 6S positive lead near the battery.
- [ ] Never power Jetson from an unverified MC02 5 V/24 V output.
- [ ] Never use J-Link VTref as a board power source.
- [ ] Never join two 5 V or 3.3 V regulator outputs together.
- [ ] All signal-linked controllers share GND.
- [ ] Do not hot-plug CAN or UART while motor power is present.
- [ ] Secure the motor and rail; remove the ball for first powered motion.
- [ ] Do not halt Ozone on a breakpoint while the motor is enabled.
- [ ] Never place, move or remove handheld meter probes on a live XT30 or
      exposed high-current output. If a voltage check is essential, disconnect
      the battery, attach insulated clip leads securely, cover exposed metal,
      check that the clips cannot bridge adjacent contacts, and only then
      energize. Disconnect power again before touching the clips.
- [ ] After the initial polarity/on/off validation has passed, use serial,
      Watch and CAN feedback for routine checks instead of repeating live
      voltage measurements.

## 2. MC02 power

The manual specifies MC02 input `12-24 V` and explicitly supports 6S.

Recommended battery tree:

```text
6S battery
  -> fuse
  -> master switch
  -> branch A: MC02 VCC_INPUT/GND
  -> branch B: fused motor power for initial CAN commissioning
  -> separate suitable regulator: Jetson
  -> separate suitable supply/regulator: TI chassis system
```

MC02 controlled output is documented as 5 A continuous per channel.
DM-J4310 nominal input is compatible with limited bench operation, but its
peak demand can exceed the documented MC02 output capability. Do not assume
the MC02 output can supply stall/impact current.

Checks before power:

- [ ] Battery is within the allowed MC02 range.
- [ ] XT30 polarity matches board `VCC_INPUT` and `GND`.
- [ ] Fuse and wire gauge are appropriate.
- [ ] No loose strands or exposed conductor can touch the PCB.
- [ ] Jetson and TI supplies are not back-feeding MC02.

## 3. J-Link SWD connection

MC02 manual SWD connector:

| MC02 SWD pin | Signal | Connect to J-Link |
|---:|---|---|
| 1 | VCC 3.3 V | VTref |
| 2 | GND | GND |
| 3 | SWCLK / PA14 | SWCLK |
| 4 | SWDIO / PA13 | SWDIO |

The four-pin MC02 SWD connector does not expose NRST. Use connect-under-reset
only if an additional verified reset connection is provided; otherwise use
normal SWD connection and the board reset button.

- [ ] Power MC02 separately from USB or its main input.
- [ ] Measure SWD pin 1 near 3.3 V before attaching J-Link VTref.
- [ ] Set Ozone device `STM32H723VG`, target interface SWD, initial speed 4 MHz.
- [ ] Load `build/Debug/gimbal_MC02.elf`.

## 4. DM4310 CAN and power

The current firmware uses FDCAN1:

```text
MC02 MCU PD0 = FDCAN1_RX
MC02 MCU PD1 = FDCAN1_TX
DM4310 CAN ID = 0x01
DM4310 Master/feedback ID = 0xF1
Classic standard CAN = 1 Mbit/s
```

### 4.1 Initial recommended wiring: motor power separate

Use this for the first CAN/feedback and small-motion tests.

- Motor power comes from a separately fused 6S branch.
- MC02 CAN1 two-pin connector:

| CAN1 pin | Signal |
|---:|---|
| 1 | CAN_L |
| 2 | CAN_H |

- Connect MC02 CAN_L to motor CAN_L.
- Connect MC02 CAN_H to motor CAN_H.
- Connect MC02 GND to motor power GND/common system GND.

This separates CAN testing from the still-uncommissioned controlled XT30
power-output path.

### 4.2 Later integrated OUT1 connector

The MC02 `VCC_OUT1 / PC14 + CAN1` XT30 2+2 port is the matching integrated
port for firmware FDCAN1:

| OUT1 pin | Signal |
|---:|---|
| 1 | VCC |
| 2 | GND |
| 3 | CAN_H |
| 4 | CAN_L |

This four-pin order follows the keyed connector front view and table on
manual page 4. It is intentionally different from the separate two-pin CAN1
connector, where pin 1 is CAN_L and pin 2 is CAN_H. Never infer either order
from wire color. The currently used keyed 2+2 cable has already passed CAN
communication testing and should not be repinned merely because an older
copy of this checklist had pins 3/4 reversed.

Do not accidentally use OUT2/CAN2; the present firmware does not initialize
FDCAN2.

Build `2026073008` keeps PC14/PC13 low at boot so both controlled 24 V
outputs default OFF. OUT2 has no enable path. The normal OUT1 path is
`PWRARM 4310` followed by `PWRON` within 3 seconds. A manual-only build with
`GIMBAL_ENABLE_MANUAL_CALRUN=1` also permits the explicit bounded
`CALRUN 4310 deg` sequence; vehicle builds must set this flag to 0. OUT1 turns
off after 300 seconds. `PWROFF`, `STOP`, any fault, non-JOG motion timeout and reset
also turn it off.
CALRUN keeps transmitting torque-disable frames while waiting up to 15 seconds
for cold-start feedback; a no-feedback timeout powers off and returns SAFE_IDLE.
For the next ball-free linkage check only, CALRUN accepts up to +/-45 degrees
with five-second legs; ordinary JOG/STEP/SWEEP remain capped at +/-10 degrees.
Use the CMake `Vehicle` preset for the disabled build; it sets
`GIMBAL_MANUAL_CALRUN=OFF` and removes the active command path.

Before ever connecting a motor to OUT1:

- [ ] Power MC02 with OUT1 disconnected.
- [ ] Run build `2026072907`.
- [ ] If measurement is still required, attach insulated meter clips from
      OUT1 pin 1 to pin 2 while all power is disconnected and secure them
      against movement or contact bridging.
- [ ] Apply power; expected boot result is approximately 0 V.
- [ ] If battery voltage appears, disconnect power and report it immediately.
- [ ] With the motor unplugged, send `PWRARM 4310`, then `PWRON`; verify OUT1
      becomes approximately the main-input voltage.
- [ ] Verify `PWROFF` immediately returns OUT1 to approximately 0 V.
- [ ] Repeat and verify automatic shutoff returns OUT1 to approximately 0 V
      after 300 seconds.
- [ ] Repeat and verify `STOP` immediately returns OUT1 to approximately 0 V.
- [ ] Disconnect battery power before removing the fixed meter clips.
- [ ] Do not repeat this full voltage sequence after it has passed unless a
      hardware fault or wiring change creates a specific need.
- [ ] Measure load current and connector/PMOS temperature during later tests.

### 4.3 CAN termination checks

With all power disconnected:

- [ ] Identify whether the motor contains/enables a 120-ohm terminator.
- [ ] Identify the MC02 CAN1 `120R` jumper/resistor state.
- [ ] Across CAN_H and CAN_L, a properly terminated two-end bus normally
      measures about 60 ohms.
- [ ] Do not install more than two 120-ohm terminators.
- [ ] Keep the first bench CAN cable short and twisted.

## 5. Jetson connection

```text
Jetson USB host -> data-capable USB cable -> MC02 USB Type-C device port
```

- [ ] Do not use a charge-only USB cable.
- [ ] Jetson sees VID:PID `0483:5740`.
- [ ] Use `/dev/serial/by-id`; do not assume `ttyACM0`.
- [ ] Camera remains connected to Jetson, not MC02.
- [ ] Jetson has its own adequate regulator and cooling.
- [ ] Jetson/MC02 binary protocol follows `JETSON_MC02_PROTOCOL_V3.md`.

USB ground provides a signal reference, but the main high-current system
ground must still be intentionally designed rather than relying on the USB
shield/cable.

### 5.1 PC commissioning console versus Jetson

The current ASCII `PING/CALRUN/STATUS/...` commissioning console is the same
native USB CDC device on the MC02 Type-C port. During bench debugging:

```text
PC USB host -> MC02 Type-C -> virtual COM port
```

During final operation:

```text
Jetson USB host -> MC02 Type-C -> V3 binary protocol
```

The MC02 has only one USB device connection and cannot be attached to the PC
and Jetson as two simultaneous USB hosts. Do not use a passive Y cable. When
Jetson owns the USB port, use J-Link/Ozone diagnostics or Jetson-side logs;
do not move the TI link onto this USB port. USB VBUS may keep MC02 logic
partially powered after the 6S battery is removed, so disconnect both battery
and USB before treating the board as fully unpowered.

## 6. TI chassis link

Preferred MC02 USART1 connector:

| MC02 pin | MC02 signal | Connect to TI |
|---:|---|---|
| 1 | USART1_TX / PA9 | TI UART1_RX / PA9 |
| 2 | USART1_RX / PA10 | TI UART1_TX / PA8 |
| 3 | GND | TI GND |

Pin numbering above follows the keyed/front view in the DM-MC-Board02 V1.1
manual: `pin 1 = PA9/TX`, middle `pin 2 = PA10/RX`, `pin 3 = GND`.

- [ ] Do not connect VCC between MC02 and TI.
- [ ] Confirm both idle TX signals are near 3.3 V.
- [ ] TI owner has added UART1 PA8/PA9 in SysConfig.
- [ ] TI owner has isolated XDS110 back-channel UART routing so there is no
      transmitter contention.
- [ ] First test at 115200 8-N-1 with both motor systems unpowered.
- [ ] Protocol follows `MC02_TI_PROTOCOL_V2.md`.
- [ ] Keep TI build `2026080104`; flash MC02 Vehicle build `2026080107`.
- [ ] With both motor rails disconnected, require MC02
      `g_gimbal_debug.ti_online=1` and increasing `ti_rx_frames`.
- [ ] Verify K1-K5 each produce the matching PREPARE, READY, three-second
      countdown, START, and eventually SAFE_STOP.
- [ ] For K2, verify TI remains disarmed at true-zero PWM until MC02's
      completed/faulted question path sends SAFE_STOP; TI's independent
      stationary-wait ceiling is 30 seconds.
- [ ] For K3, verify B_MARKER_PASSED at 1500 mm and calibrate the physical
      stop point before accepting the nominal encoder distance.
- [ ] Verify disconnecting one UART signal during an active raised-wheel test
      stops the chassis within 500 ms.

### 6.1 TI Button X8 panel

Confirmed logical mapping:

| Button | Function |
|---:|---|
| K1 | internal question 1 / printed requirement 2 |
| K2 | internal question 2 / printed requirement 3 |
| K3 | internal question 3 / printed requirement 4 |
| K4 | internal question 4 / printed requirement 5 |
| K5 | internal question 5 / printed requirement 6 |
| K6 | toggle TI chassis software-power permission; OLED `PWR 0/1` |
| K7 | normal stop/reset back to question-selection standby |
| K8 | emergency stop |

- [x] TI source assigns K1 PA10/BP34, K2 PA11/BP33, K3 PB13/BP35,
      K4 PB20/BP36, K5 PA31/BP37, K6 PA28/BP38, K7 PB12/BP19 and
      K8 PB15/BP17. Every input is active-low with an internal pull-up.
- [x] TI source debounces every press/release for 40 ms and emits `0xA2`.
- [x] K6 can enable only while both endpoints are online/idle. K6-off,
      SAFE_STOP, K7, K8, fault and link loss all restore `PWR 0`; this does
      not physically disconnect the chassis 12 V rail.
- [x] K7 source removes chassis motor authority on the first raw-low sample
      before its debounced event.
- [x] K8 source does the same and latches emergency stop.
- [x] Source logic prevents K8 release from restarting and requires K7 after
      K8 release to return to standby.
- [ ] The eight physical wires, all `0xA2` events, true-zero PWM behavior and
      latch/reset sequence have not yet been checked on hardware.
- [ ] K8 is currently connected only to TI, so it cannot guarantee gimbal
      shutdown if UART fails.
- [ ] Retain an accessible master power disconnect, or add an independent
      hardwired stop path to MC02, before calling K8 a whole-system hard
      emergency stop.

### 6.2 Ports intentionally unused in the current architecture

- USART1 is reserved exclusively for the TI link.
- UART7 and UART10 are not used.
- OUT2/CAN2, CAN3, both RS485 ports, SBUS and the four PWM outputs are not
  used.
- The onboard BMI088 IMU needs no external wire and is not used by the
  current firmware.
- Do not connect any unused 5 V pin to Jetson, TI, J-Link or another
  regulator output.

## 7. First power-on inspection sheet

Record actual measurements:

| Item | Expected | Measured |
|---|---:|---:|
| MC02 main input | 6S battery, within 12-24 V | |
| SWD VTref | about 3.3 V | |
| OUT1 VCC-GND at boot on build 2026073008 | about 0 V | |
| OUT1 VCC-GND after guarded PWRON | main-input voltage | |
| OUT1 after 180 s/PWROFF/STOP | about 0 V | |
| OUT2 VCC-GND on build 2026073008 | about 0 V | |
| CAN_H-CAN_L resistance, power off | about 60 ohm if two terminators | |
| MC02 USART1 TX idle (build 2026073106) | about 3.3 V | |
| TI UART1 TX idle | about 3.3 V | |

Photograph the wiring and fill this table before the first motor-enable test.

## 8. Commissioning order

### Stage A - logic only

- [ ] Motor power disconnected.
- [ ] Build and flash the Vehicle image `2026073106`.
- [ ] Ozone Watch shows `g_gimbal_debug.build_id = 2026073106`.
- [ ] `state = SAFE_IDLE`, `fault = 0`.
- [ ] Startup `can_tx_count` increases by at least five disable attempts.
- [ ] Watch shows `power_output_enabled = 0`.
- [ ] With the motor unplugged, perform one fixed-clip validation of guarded
      OUT1 on, PWROFF, 300-second timeout and STOP; do not move probes live.

### Stage B - CAN observe only

- [ ] Secure motor; rail/ball removed or restrained.
- [ ] Connect the keyed OUT1/CAN1 2+2 cable only after unloaded output tests.
- [ ] Keep a hand on the master switch.
- [ ] Send `PWRARM 4310`, then `PWRON`; wait at least 600 ms.
- [ ] Send `PING`, then `OBSERVE`, then `STATUS`.
- [ ] Require `ONLINE=1`, `RX` increasing and motor state 0/disabled.
- [ ] Confirm that any enabled-state or fault feedback during OBSERVE
      immediately switches OUT1 off and enters MC02 FAULT.
- [ ] Do not continue if motor red LED flashes or CAN feedback is stale.

### Stage C - bounded motor motion

- [ ] Send `ARM`, then `HOLD`; expect no large movement and auto-stop at 15 s.
- [ ] Send `OBSERVE`, `ARM`, `STEP 10`.
- [ ] Send `OBSERVE`, `ARM`, `STEP -10`.
- [ ] Record physical direction and feedback sign.
- [ ] Only after both directions pass, test `SWEEP 1.0`.
- [ ] `STOP` remains ready in the terminal.

### Stage D - fault tests

- [ ] Verify command timeout auto-disables.
- [ ] Verify manual STOP.
- [ ] After normal 10 ms CAN control is proven, restore motor CAN Timeout to
      2000 and deliberately unplug CAN to verify independent motor protection.
- [ ] Record motor LED/error code and MC02 fault state.

### Stage E - communications

- [ ] Jetson protocol parser/CRC loopback test before any vision control.
- [ ] Stream recorded/synthetic ball samples while motor remains disabled.
- [ ] TI protocol test through USB-UART adapters with chassis motor power off.
- [ ] Verify TI supervisor-heartbeat loss stops PWM within 500 ms.
- [ ] Join MC02 and TI only for the motor-power-off link test first.

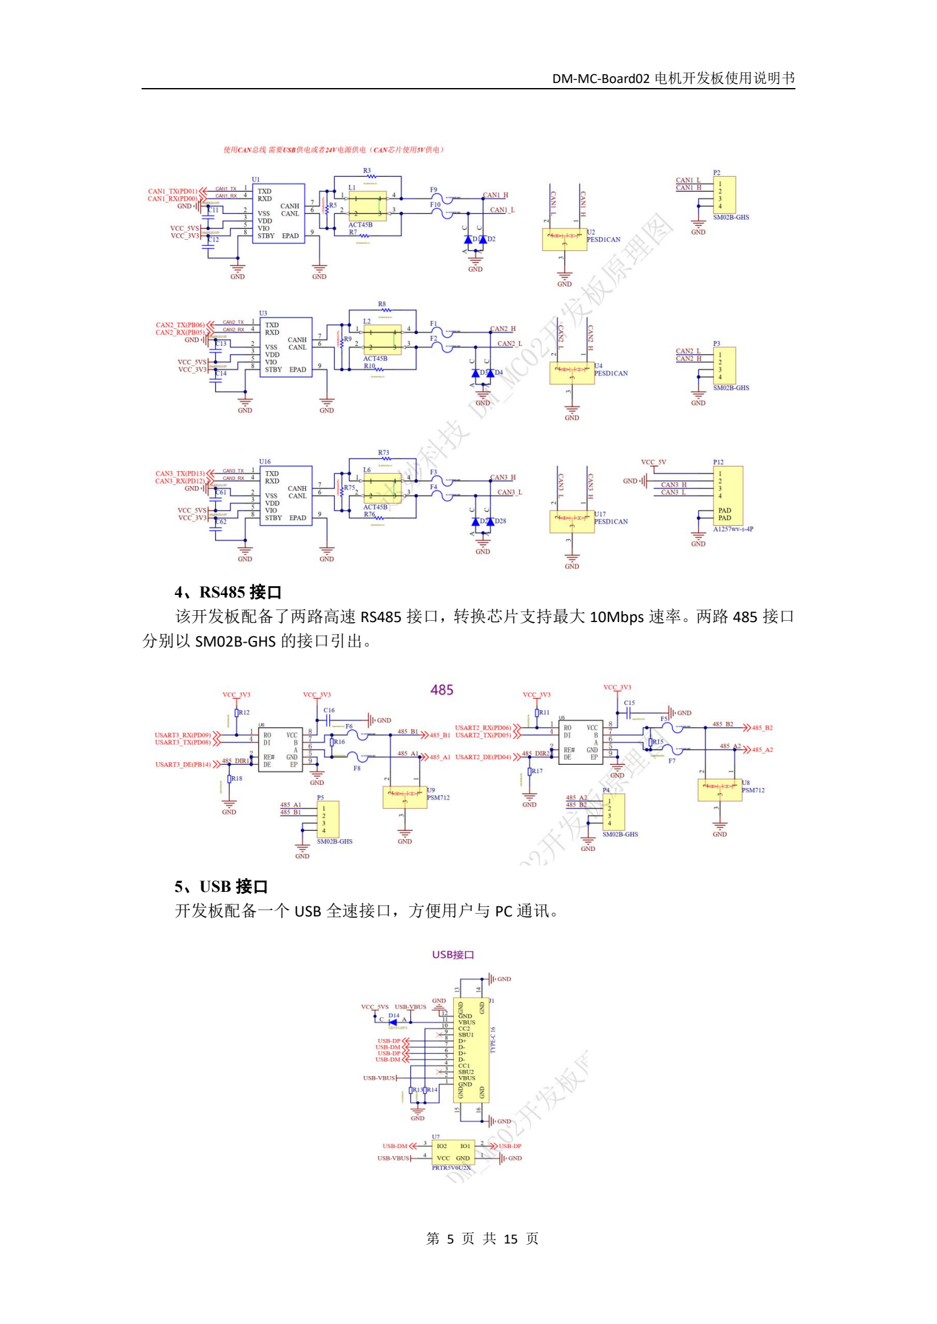
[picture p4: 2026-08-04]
gimbal_MC02/tmp/pdfs/mc02_manual/page_7.png

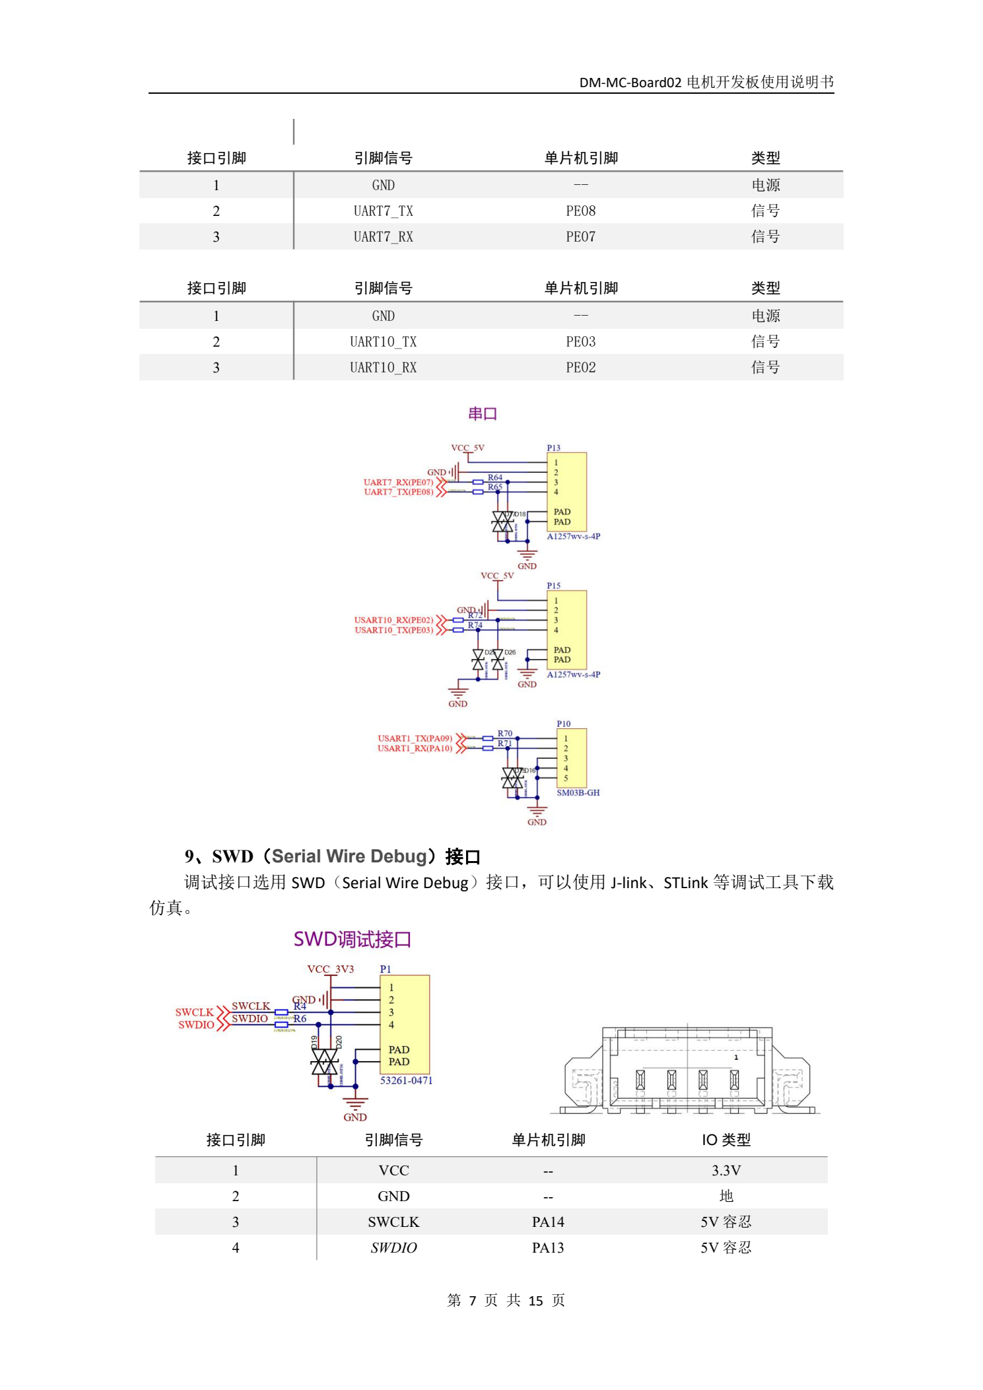
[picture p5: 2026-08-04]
gimbal_MC02/tmp/pdfs/mc02_manual/page_9.png

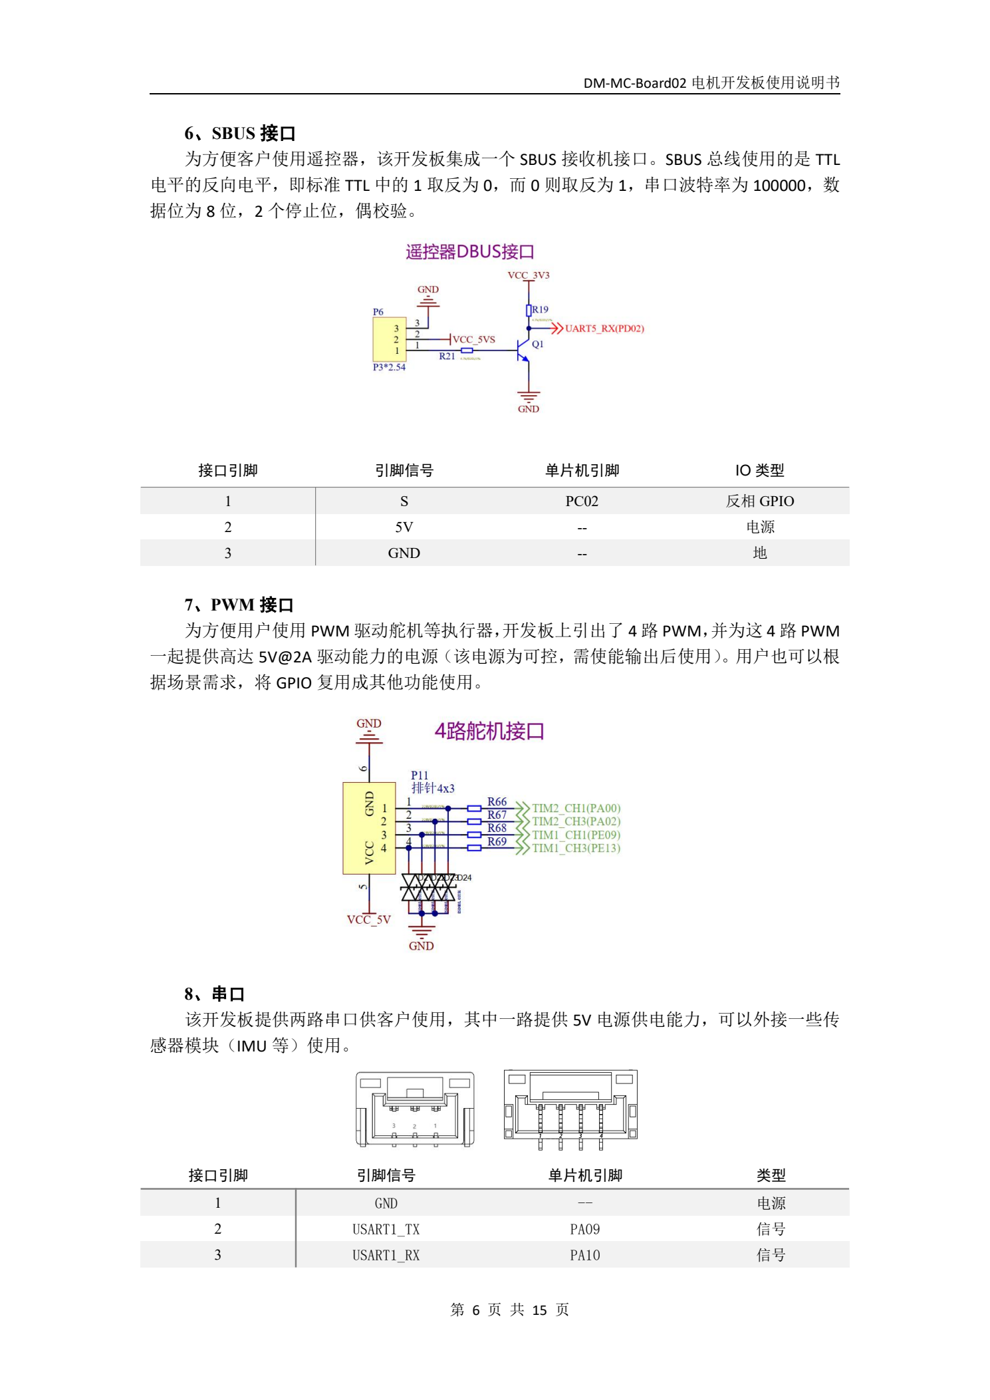
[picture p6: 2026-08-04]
gimbal_MC02/tmp/pdfs/mc02_manual/page_8.png

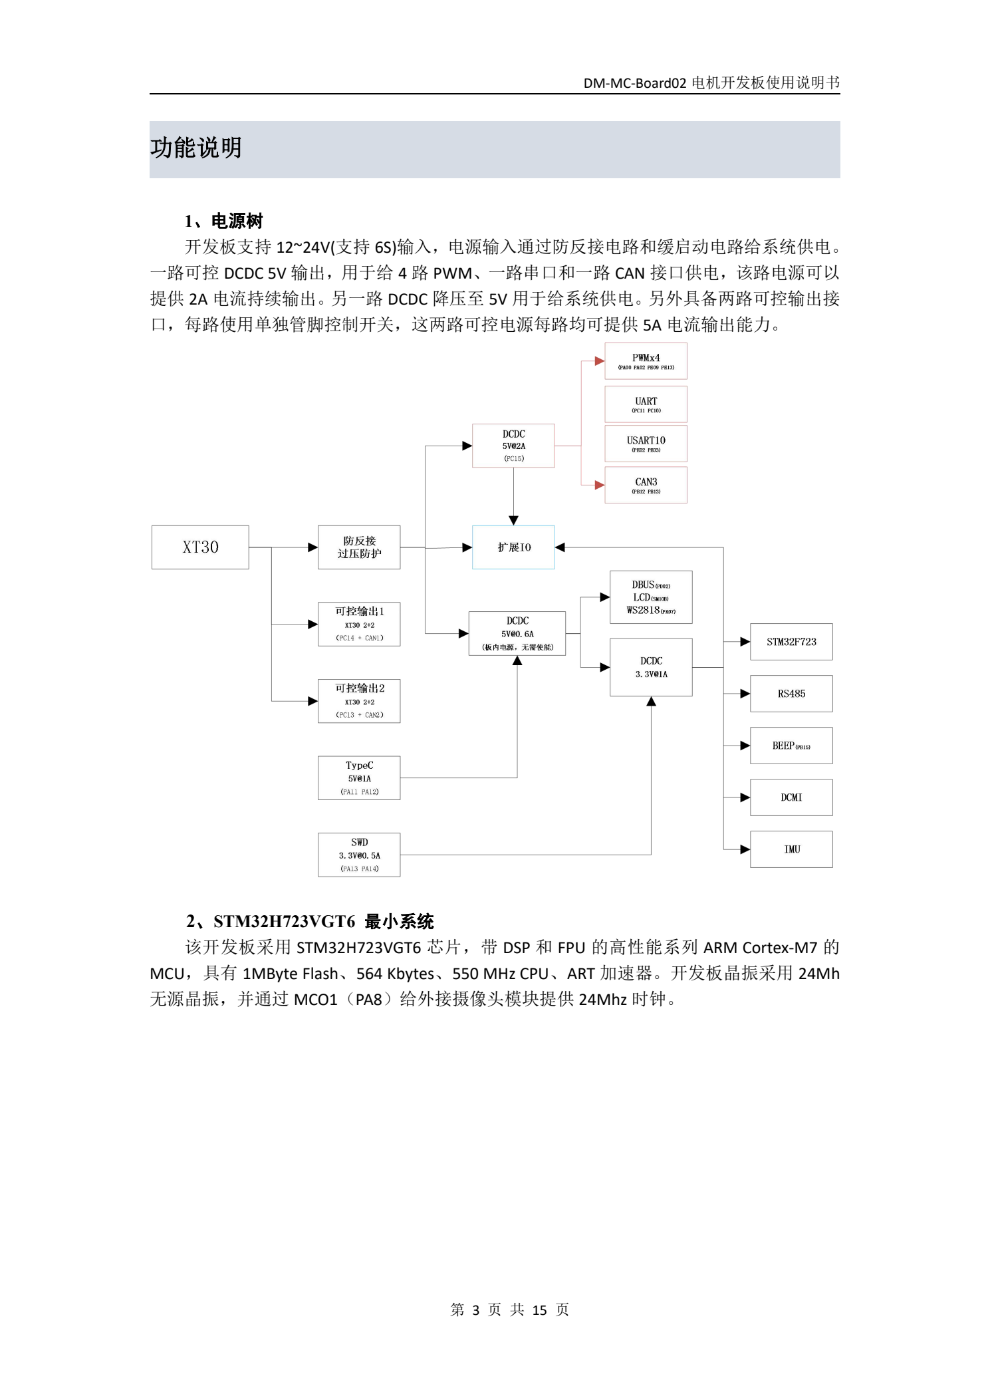
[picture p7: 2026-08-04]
gimbal_MC02/tmp/pdfs/mc02_manual/page_5.png

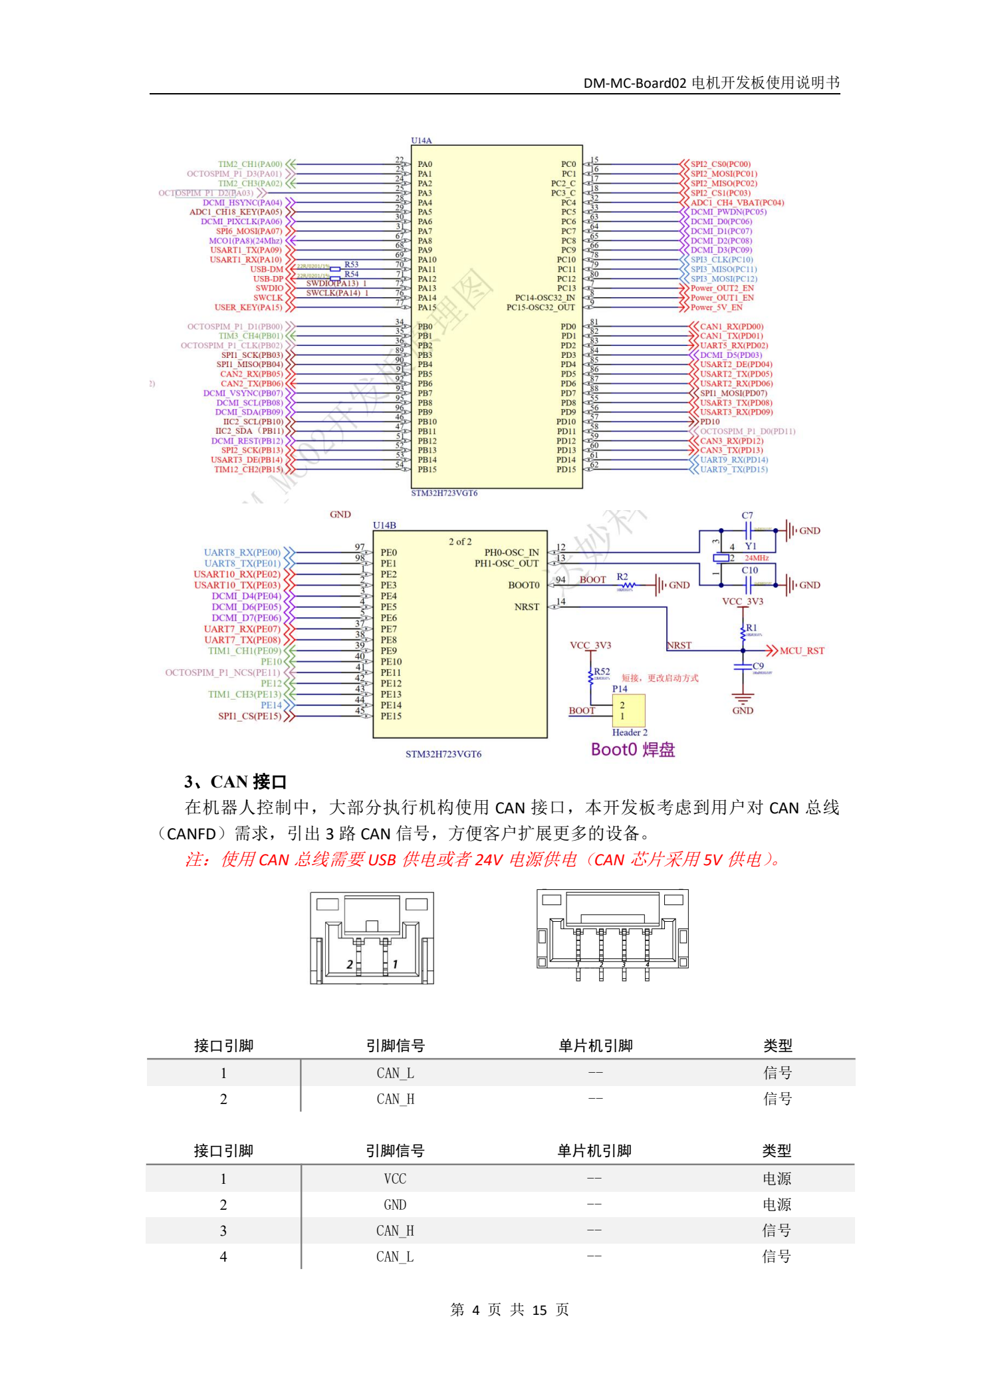
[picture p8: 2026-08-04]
gimbal_MC02/tmp/pdfs/mc02_manual/page_6.png

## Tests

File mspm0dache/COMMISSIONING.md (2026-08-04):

# Hardware commissioning and calibration

## Non-negotiable electrical limits

### Encoder signals

The installed encoders require a stable 5 V VCC and have push-pull A/B
outputs. Treat every raw A/B output as potentially 5 V. Route all four A/B
signals through proper unidirectional 5 V-to-3.3 V level translation before
the MSPM0 pins unless measurement proves that the actual output-high voltage
does not exceed 3.3 V.

Before connecting A/B to the LaunchPad:

1. Power the encoder.
2. Rotate the shaft slowly.
3. Measure the high level of A and B with an oscilloscope or multimeter.
4. Connect them only after both have been verified at no more than 3.3 V.

A 5 V push-pull output must not be connected directly to MSPM0 GPIO.

### 6S battery and 12 V motors

A 6S LiPo is about 22.2 V nominal and 25.2 V fully charged. The MG513XP28
motors are rated for 12 V. Use:

```text
6S battery
  -> main fuse and physical master switch
  -> high-current regulated 12 V converter
  -> DRV8701E motor power input
  -> two 12 V motors
```

The DRV8701E board accepting a higher voltage does not make a 12 V motor safe
at 25.2 V. The LaunchPad and encoder rails also require their own correct
regulated supplies. All control grounds must share a reference, while motor
current must not return through thin MCU or encoder ground wiring.

There is no physical GPIO emergency-stop input in this firmware. A reachable
master switch or hard motor-power disconnect is therefore required.

## Onboard XDS110 connection

The current workflow uses the LaunchPad onboard XDS110. Restore every J101
jumper to its factory-installed position, leave J102/J103 unused, and do not
inject external 3.3 V into J11 during USB-powered development.

Connect the LaunchPad Micro-USB debug connector to the PC. Build and download
from VS Code with `Build and Flash MSPM0 (onboard XDS110)`, or run:

```powershell
C:\ti\ccs\utils\bin\gmake.exe -C . flash
```

Ozone does not support XDS110. Use CCS Expressions for live `g_test` writes;
source editing and Makefile builds remain in VS Code.

## Phase A: MCU only

1. Disconnect the DRV motor-power input.
2. Build and download `ticlang/mspm0dache.out`.
3. Reset the MCU.
4. Confirm in CCS Expressions:

```text
g_test.build_id == 2026080104
g_test.mode == 0
g_test.arm == 0
g_test.status == 0
```

5. Check PA12, PA13, PB4, and PB1 with a scope. All four must remain at 0 V
   after reset and while mode 0 is selected.

## Phase B: encoder scale and direction

Keep motor power disconnected.

1. Supply the encoders with a verified 5 V rail and verify the translated
   A/B levels presented to the LaunchPad are no more than 3.3 V.
2. Set `g_test.mode = 2` to clear both totals.
3. Set `g_test.mode = 1`.
4. Mark the left tire and rotate it exactly one full output-wheel revolution
   in the vehicle-forward direction.
5. Record `g_test.left.encoder_count`.
6. Reset again and repeat for the right wheel.

The 2026-07-25 ten-revolution measurements produced left 1467.475 and right
1467.95 counts per revolution; firmware build 2026072504 uses left 1467 and
right 1468. If the encoder or gearbox is replaced, measure the absolute values
again rather than relying on the nominal calculation. Update:

```c
ENCODER_LEFT_COUNTS_PER_WHEEL_REV
ENCODER_RIGHT_COUNTS_PER_WHEEL_REV
```

in `chassis_config.h`.

Forward wheel rotation should produce positive corrected totals. If it is
negative, change only the corresponding `ENCODER_*_REVERSED` flag and repeat.
Do not hide a channel swap by changing several sign flags at once.

`g_test.left_invalid_transitions` should remain close to zero during slow hand
rotation. A rapidly increasing value indicates noise, incorrect pull
configuration, or missed software-decoder transitions.

## Phase C: PWM and direction without motor power

1. Disconnect all power. Use continuity mode to prove PA12/BP32 reaches only
   PWM1, PB4/BP40 reaches only DIR1, PA13/BP31 reaches only PWM2, and
   PB1/BP39 reaches only DIR2. Do not infer the mapping from wire colors or
   connector orientation.
2. Connect DRV GND, PWM1, DIR1, PWM2, and DIR2.
3. Leave the DRV motor-power input disconnected.
4. In mode 0, verify PA12, PA13, PB4, and PB1 are all 0 V.
5. Set `g_test.duration_ms = 2000`.
6. Arm and run mode 3. Verify only PA12 has 20 kHz, 15% PWM.
7. Return to mode 0 and verify all four lines return to 0 V within 10 ms.
8. Arm and run mode 4. Verify only PA13 has 20 kHz, 15% PWM, then repeat the
   mode-0 all-low test.
9. Verify direction changes occur only while PWM is removed. The firmware
   waits at least 1000 ms for coast-down, requires measured speed below 2 RPM,
   and then gives DIR 10 ms of setup time before PWM resumes.

## Phase D: lifted-wheel motor test

1. Secure the chassis with both drive wheels off the floor.
2. Set the converter to a measured 12.0 V before connecting the DRV.
3. Open-loop diagnostic modes use a fixed 15% PWM.
4. Run mode 3 and mode 4 separately.
5. Positive PWM must rotate each physical wheel in the vehicle-forward
   direction, and its corrected encoder count must also increase.
6. Run mode 5 briefly.

If a motor direction is wrong, update the corresponding
`MOTOR_*_OUTPUT_REVERSED` flag or deliberately swap that motor's power leads.
Document which choice was made.

## Phase E: closed-loop tuning

Do not tune PID until CPR and direction are correct.

1. Set `target_rpm = 40`, `duration_ms = 5000`.
2. Arm and run mode 7.
3. Observe `g_test.left/right.rpm`, `error_rpm`, `pwm`, `integral`, and
   `pid_output`.
4. Change `g_test.left/right.kp/ki/kd` only while stopped. The gains are
   validated and applied when the next mode-7 run starts.

Mode 7 requires both encoders to keep producing counts in the commanded
direction. Its duration must be at least 2000 ms. Status `-4` indicates
encoder progress was lost or had the wrong sign; `encoder_fault_mask` bit 0
is left and bit 1 is right. Stop and diagnose sign configuration, wiring,
supply level, signal quality, or mechanical binding before retrying.

The 750 ms progress window starts only after actual PWM resumes following any
direction-change hold. `encoder_verified_mask` uses the same left/right bits;
mode 7 cannot report success until both bits have passed a complete window.
After a wheel's first window starts, supervision never pauses. Status `-5`
means actual output did not start before timeout or had the wrong sign;
`output_fault_mask` uses bit 0 for left and bit 1 for right.

Treat `g_test.status` as read-only telemetry. Editing it does not control the
private running state or disable the timeout.

The 40% closed-loop PWM cap is enforced inside the motor layer and is not
debugger-writable. Stop the test before changing target direction or gains.

The initial PID is provisional and expressed in seconds:

```text
Kp = 0.7
Ki = 20.0
Kd = 0.0
control period = 0.010 s
```

Record final left and right values in `AGENT.MD`.

Distance and turn command modes are intentionally deferred until encoder
counting and mode-7 PID commissioning pass.

## Phase F: MC02-supervised KEY1/OLED test

Build 2026080104 has `STANDALONE_KEY1_START=0`; MC02 heartbeat plus the
PREPARE/READY/START handshake is required. KEY1 only sends the debounced
button event and never directly grants PWM authority. The OLED stopwatch
starts at accepted Q2 execution, or for a moving question only after the
fresh-sensor gate succeeds and the motor controller is armed.

1. Keep the drive wheels raised and place a valid centered line under S4/S5.
2. Press/release KEY1 once. `status=3` and `start_delay_ms` counts down from
   3000 while both PWM outputs remain zero.
3. After the countdown, five newly acquired valid sensor samples are required
   within 500 ms. Only then may the motors arm.
4. Motion begins at 30 RPM for one second, remains at most 55 RPM through the
   first 300 mm, then ramps toward the formal 120 RPM/100 RPM profile.
5. Press KEY1 again during countdown or motion. It must cancel/stop and
   disarm immediately.
6. Without another press, the local course run must stop by 20,000 ms.

First connect only the crossed 3.3 V UART TX/RX and common GND with both motor
systems unpowered. Verify increasing `g_test.mc02.rx_frames` and
`g_test.mc02.online=1` before a raised-wheel Q1 test.

K7/K8 are not connected in this build. Keep the physical motor-power master
switch reachable.

## Phase G: Bluetooth temporarily disabled

The JDY-31 has been unplugged. UART0 and `bluetooth.c` are excluded from build
2026073006; PA10 is reassigned to SW1. Do not reconnect the JDY-31 to PA10
while this build is installed. The Bluetooth sources and PC helper remain in
the repository only for possible later restoration.

## Phase H: Hiwonder 8-channel line-sensor input

Build 2026080104 configures the guarded formal-course line-following controller
for MC02-supervised KEY1 start and a 40-second Q1 safety timeout; the scored
completion target remains 20 seconds.

1. Keep motor power disconnected and leave PB2/PB3 disconnected.
2. Power the `LineFollower_8CH V1.0` from a stable regulated 5 V rail and
   connect its GND to system GND.
3. Measure idle `SCL` and `SDA` at the sensor against GND. Both must be no
   higher than 3.3 V before direct connection to the MSPM0. If either is
   higher, insert a bidirectional I2C level shifter.
4. With power off, connect sensor `SCL` to PB2/BP9 and sensor `SDA` to
   PB3/BP10. Leave S1-S8 and TX/RX disconnected.
5. Flash build 2026080104. The already completed debugger tests established a
   working I2C link and the channel mapping; no debugger cable is required for
   the following motion tests.
6. Mount the array at a fixed height within the documented 0.5-8 cm range.
   Calibrate the background first by holding KEY, then place it over the
   target line and briefly press KEY.
7. Move each of S1-S8 over the learned line one at a time. Record bit order,
   bit polarity, analog response, threshold values, and which end of the
   board is physically left when the vehicle faces forward.

8. For the first motion check, raise the drive wheels while keeping the sensor
   at its calibrated track gap, then press KEY1. TI requires five newly acquired valid
   samples before arming and uses 30 RPM for the first second, 55 RPM for the
   first 300 mm, then Q1 uses 143 RPM straight base and 110 RPM curve floor,
   steering Kp 12/Kd 6,
   and an 80 RPM/s acceleration limit.
9. Centered line must produce equal targets. S1 must lower the left target and
   raise the right; S8 must do the opposite. Removing the line must stop and
   disarm with status -6 after 100 ms.
10. Press KEY1 again to end the raised-wheel test early. Only after these
    checks pass may Q1 be tested on the course with the bounded 40-second
    safety run while recording whether it meets the scored 20-second target.
    PID/output/encoder, sensor-loss, and
    duration-stop protections remain active.
11. Formal geometry is two 1500 mm straights and two radius-500 mm
    semicircles, giving 6141.6 mm centerline length and a 2500 x 1000 mm
    outer envelope. The first 100 mm from the transverse start bar uses equal
    wheel targets before centroid steering begins. After the two-turn/distance
    gate near A, the vehicle follows 150-250 mm into the next straight,
    requires eight fresh centered one/two-channel samples, stops and settles
    below 2 RPM, then reverses at equal 25 RPM. A is accepted when at least
    three channels are simultaneously active in three consecutive fresh
    samples. The 120 ms union is telemetry only. Missing A at 400 mm reverse
    or 6 seconds is a timeout, never permission for a second lap. Record `turn_count`,
    `lap_yaw_deg`, `lap_distance_mm`, `lap_phase`, `finish_distance_mm`,
    `marker_recent_state/count`, final status and measured stop offset.
12. Q3 drives the measured 1500 mm A-B route and then ramps to zero. Q4/Q5
    finish after the existing one-lap turn/distance gate; they do not perform
    Q1's reverse-marker sequence. Q3 retains 100 RPM cruise with 30 RPM/s
    common acceleration/deceleration. Q4/Q5 use 70 RPM cruise with 14 RPM/s
    common acceleration/deceleration. Their steering difference retains the
    300 RPM/s slew. Verify Q3 completes and settles within 8 s and Q4/Q5
    within 30 s while filming the payload.
13. During every accepted run, verify the OLED integer seconds advance once
    per second and freeze when the chassis finishes or is stopped.

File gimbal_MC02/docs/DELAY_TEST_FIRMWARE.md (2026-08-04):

# 全环路延迟专用固件

适用 MC02 build `2026073106` 的 `DelayTest` 构建。它只用于
《现场测量手册》第三部分的 `total_delay_ms` 测量，不是比赛固件。

## 固定测试动作

- 管道指令：`0 -> -1.5 deg -> 0`
- `-1.5 deg` 保持：`500 ms`
- DM4310 `v_des`：`12.0 rad/s`
- V3 `0x81 GIMBAL_STATUS`：`100 Hz`
- V3 帧格式、字段、单位、符号和 CRC 完全不变
- 没有任意角度入口，没有方波或自动重复入口

按已测传动比 `pipe/motor = 0.044`，`-1.5 deg` 管道角对应约
`+34.1 deg` 电机角。这个速度和已装机构的实际安全性不能由编译证明，
所以固件强制先运行一次完全相同的空载脉冲，并等待人工确认。

## 构建和烧录

```powershell
cd C:\Users\Han\Desktop\dIANSAI\diansai(1)\gimbal_MC02
cmake --preset DelayTest
cmake --build --preset DelayTest --clean-first
```

烧录：

```text
build/DelayTest/gimbal_MC02.elf
```

上电运行后，在 Ozone Watch 确认：

```text
g_gimbal_debug.build_id = 2026073106
g_gimbal_debug.delay_test_enabled = 1
g_gimbal_debug.delay_test_phase = 0
```

`Debug`、`Release` 和 `Vehicle` 构建中的
`delay_test_enabled` 都必须为 `0`。不要把 `DelayTest` 镜像用于比赛。

## Ozone 请求值

Ozone 在 CPU 运行时不能直接编辑 Watched Data 的 Value 单元格。必须打开
`gimbal_MC02_DelayTest.jdebug`，在 Ozone Console 通过内置
`Script.Exec` 调用工程里的辅助函数：

```text
Script.Exec("DelayTestPrepare")
Script.Exec("DelayTestValidateEmpty")
Script.Exec("DelayTestAckMechanical")
Script.Exec("DelayTestMeasure")
Script.Exec("DelayTestStop")
```

前四个辅助函数会使用 `Target.WriteU32` 后台内存访问连续写入 key 和 request，
CPU 和全部看门狗保持运行；STOP 只写 request `5`。固件会自动清零 key 和
request。不要暂停 CPU、打断点或单步执行带电动作。

每次被接受的空载验证、机械确认或正式测量请求都会把有界 OUT1 保护重新设为
300 秒；被拒绝的请求不会续期。若操作者连续300秒没有执行有效阶段动作，固件
仍会进入 phase 8、关闭 OUT1。这样可以完成8～10次测量，同时不会取消无人值守
超时。

| request | 含义 | 接受条件 |
|---:|---|---|
| 1 | PREPARE | SAFE_IDLE、无故障、没有比赛/CALRUN |
| 2 | VALIDATE_EMPTY | phase=3，球已取走，机构运动区域净空 |
| 3 | ACK_MECHANICAL | phase=6，操作者确认空载动作无碰撞/卡滞 |
| 4 | MEASURE | phase=7，视觉有效、球在中心且基本静止 |
| 5 | STOP | 随时接受，不需要 key，立即失能并关闭 OUT1 |

`delay_test_phase`：

| phase | 含义 |
|---:|---|
| 0 | IDLE |
| 1 | 等待 OUT1/DM4310 反馈 |
| 2 | 3 秒倒计时并保持零位 |
| 3 | 等待空载验证脉冲 |
| 4 | `-1.5 deg` 脉冲进行中 |
| 5 | 返回零位并确认稳定 |
| 6 | 空载验证完成，等待人工确认 |
| 7 | 可以触发带球测量 |
| 8 | 测试故障，需先清故障 |

## 首次空载验证

1. 取走球，架空/固定整车，确认传动和管道周围无人、无工具和线缆干涉。
2. 保证 K8/总急停可立即操作；Ozone 保持 Run，禁止断点。
3. 在 Ozone Console 执行 `Script.Exec("DelayTestPrepare")`。
4. 等待 `delay_test_phase = 3`，同时确认：
   - `fault = 0`
   - `feedback_age_ms <= 80`
   - `motor_error = 1`
   - `level_zero_valid = 1`
5. 在 Ozone Console 执行
   `Script.Exec("DelayTestValidateEmpty")`。固件只执行一次
   `0 -> -1.5 deg（500 ms）-> 0`。
6. 等待 `delay_test_phase = 6`。检查无碰撞、无卡滞、无松脱、方向正确，
   并且最终回到零位。任何异常立即 request `5` 或按 K8，禁止确认。
7. 确认机械动作正常后，在 Console 执行
   `Script.Exec("DelayTestAckMechanical")`；
   `delay_test_phase` 应变为 `7`。

空载验证没有通过就不能进入带球测量。一次 STOP、故障、复位或重新烧录
都会清除这次确认，必须重新空载验证。

## 带球测量

1. Jetson 保持发送 V3 HEARTBEAT 和 VISION_SAMPLE，并确认相机、检测器、
   标定三项 ready。
2. 临时把
   `competition/competition/config/control.yaml` 中
   `estimator.r_meas_cm` 改为 `0.001`。
3. 把球放回 O 点并保持静止。MC02 要求 `|x| <= 10 mm`，连续至少
   8 个有效样本，并在连续 `300 ms` 内观察到的位置跨度不超过 `2 mm`。
   观察 `delay_test_stable_ready = 1` 后才能触发；视觉无效、超出中心、
   样本中断或位置跨度超限都会重新开始稳定计时。
4. 开始视觉侧数据记录。
5. 在 Console 执行 `Script.Exec("DelayTestMeasure")`。固件执行一次固定
   脉冲并自动返回零位。
6. 等待 `delay_test_phase` 回到 `7`；
   `delay_test_measurement_count` 应增加 1。
7. 将球重新放回 O 点并静止，重复步骤 4–6，共做 8–10 次。
8. 用视觉侧 `tools/meas_delay.py` 逐次计算，最终取中位数写入
   `total_delay_ms`。恢复真实的 `r_meas_cm`。

当前 Windows 交接副本中没有 `tools/meas_delay.py`，运行测量前应从视觉同学
取得与《现场测量手册》一致的脚本，不能用不存在的本地路径代替。

## 自动拒绝和停机条件

- 带球触发前视觉无效、未标定、置信度不足、位置或连续稳定窗口不满足：只拒绝，
  `delay_test_denied_count` 增加，不产生动作。
- 动作期间 DM4310 反馈超过 `80 ms`、电机报告异常、CAN 发送失败、
  Jetson/视觉丢失、返回零位超过 `2 s`：失能、关闭 OUT1并进入故障。
- TI K7/K8、安全停机、普通 Ozone STOP、delay request `5`、复位：
  都会终止测试并清除机械确认。

编译通过只说明源码可以生成镜像，不代表高速空载动作或全环路测量已经在
实车上验证。

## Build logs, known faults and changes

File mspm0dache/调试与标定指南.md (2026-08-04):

# mspm0dache 调试与标定指南

本指南适用于 LP-MSPM0G3507、双路逐飞 DRV8701E、两台
MG513XP28_12V 电机和 13 PPR 霍尔编码器。当前固件使用 LaunchPad 板载
XDS110 和 Micro-USB 下载；外接八键板 SW1 接 PA10/BP33。build
`2026073005` 中启用 KEY1 独立测试：按键本地启动/停止底盘，不等待 MC02，
但仍不能代替物理急停。

## 1. 上电前必须确认

### 编码器只能向 MCU 输出不高于 3.3 V 的信号

- 两个编码器均使用稳定的 **5 V** 供电。
- 接入 LaunchPad 前，缓慢转动电机，用示波器或万用表分别测量四路
  A/B 原始信号；按推挽 5 V 输出处理，并让四路信号经过合适的
  5 V 转 3.3 V 单向电平转换器。MCU 侧高电平必须不超过 3.3 V。
- **5 V 推挽输出不得直连 MSPM0 GPIO。**

### 6S 电池不能直接驱动 12 V 电机

6S 锂电池标称约 22.2 V，满电约 25.2 V，而电机额定电压为 12 V。
电源链路必须为：

```text
6S 电池
  -> 主保险丝 + 可触及的物理总开关
  -> 足够电流能力的稳压 12 V 降压模块
  -> DRV8701E 电机电源
  -> 两台 12 V 电机
```

- DRV8701E 本身能承受较高电压，不代表 12 V 电机可以承受 25.2 V。
- LaunchPad 和编码器也必须使用各自正确的稳压电源。
- 控制地必须共地，但电机大电流不能经过 MCU 或编码器的细地线回流。
- 固件没有物理急停输入，因此必须保留可立即切断电机电源的总开关。
- **电机电源接通时禁止打断点或暂停 CPU。** CPU 停止后超时保护无法执行，
  PWM 定时器还可能停在高电平。带电测试只用 Expressions 动态观察，不使用断点。

## 2. 板载 XDS110 与 USB

把 J101 全部跳帽恢复到出厂安装状态，J102/J103 保持悬空，不向 J11 注入
外部 3.3 V。只需使用开发板自带的 Micro-USB 线连接电脑和 LaunchPad 的
板载 XDS110 USB 口。

在 VS Code 中运行任务 `Build and Flash MSPM0 (onboard XDS110)`，或执行：

```powershell
C:\ti\ccs\utils\bin\gmake.exe -C . flash
```

Ozone 不能使用 XDS110。需要动态写入变量时，用 CCS 调试器的 Expressions
视图；源码编辑和 Makefile 编译仍在 VS Code。

## 3. 编译、下载与调试变量

在 VS Code 中按 `Ctrl+Shift+B`，选择 `Build MSPM0 (TEST_MODE)`；也可在
工程根目录运行：

```powershell
C:\ti\ccs\utils\bin\gmake.exe -C . -j4
```

下载 `ticlang\mspm0dache.out` 后，在 CCS Expressions 中加入：

```text
g_test
```

调 PID、控制测试和截图都只使用这一个结构体。停车时可以修改
`duration_ms`、`target_rpm` 和 `left/right.kp/ki/kd`；左右轮下面的
编码器计数、转速、误差、PWM、积分和 PID 输出均为实时数据。

复位后必须确认：

```text
g_test.build_id == 2026073005
g_test.mode == 0
g_test.arm == 0
g_test.status == 0
PA12、PA13、PB4、PB1 均为低电平
```

## 4. 调试器下发命令的固定顺序

每次运动命令都严格按以下顺序写入：

1. 先填写全部参数。
2. 写 `g_test.arm = 1`。
3. **最后**写 `g_test.mode`。
4. 固件接收后会自动清除 `arm`。
5. 达到目标、发生故障或超时后，固件会停止并解除使能。

任何时候写 `g_test.mode = 0`，都会在最长 10 ms 内停止并解除使能。版本
`2026072504` 在解除使能时会把 PA12、PA13、PB4、PB1 四根控制线全部切换为
GPIO 低电平；每个 PWM 通道命令为 0 时也会单独切换为 GPIO 低电平。重新完成
断电测量前，不能把软件停机当作物理急停。

| mode | 功能 | 需要 `arm=1` |
|---:|---|:---:|
| 0 | 停止并解除使能 | 否 |
| 1 | 停止，仅观察编码器数据 | 否 |
| 2 | 清零左右编码器累计值 | 否 |
| 3 | 仅右轮，正向开环 PWM | 是 |
| 4 | 仅左轮，正向开环 PWM | 是 |
| 5 | 双轮正向开环 PWM | 是 |
| 6 | 双轮反向开环 PWM | 是 |
| 7 | 双轮按 `target_rpm` 闭环 | 是 |
| 8 | 低速黑线循迹 | 是 |

| status | 含义 |
|---:|---|
| -6 | 巡线传感器断连、采样停滞或连续丢线 100 ms |
| -5 | 必需的电机输出未能启动，或实际输出方向错误 |
| -4 | 必需的编码器无计数、停止计数或方向错误 |
| -3 | 参数非法 |
| -2 | 运动超时 |
| -1 | 未先置 `arm=1` 就请求运动 |
| 0 | 空闲 |
| 1 | 运行中 |
| 2 | 已完成 |
| 3 | 等待启动/确认新的有效巡线采样 |

固件安全限制：

- 开环诊断固定使用 15% PWM。
- 模式 3-7 单次最大 30000 ms；模式 8 总上限 120000 ms，MC02 第一问
  命令最多 20000 ms。
- 模式 7 的时长不能小于 2000 ms，闭环输出绝对上限为 40% PWM。
- 模式 7 要求两个编码器沿命令方向持续计数；状态 `-4` 时，
  `encoder_fault_mask` 的 bit 0 表示左轮、bit 1 表示右轮。
- 状态 `-5` 时，`output_fault_mask` 的 bit 0 表示左轮、bit 1 表示右轮。
- 每个车轮的首个 750 ms 编码器监督窗只在换向等待结束、实际 PWM 已恢复后
  开始；一旦开始就不会再暂停。之后若无持续运动，最多 750 ms 报错，非零
  反向输出则立即报错。模式 7 必须让 `encoder_verified_mask` 的左右两个
  bit 都通过完整监督窗，才能成功。
- 模式 7 运行期间不能直接改变方向或 PID 参数。
- 反向前会先撤掉 PWM，固定至少滑行 1000 ms，随后还必须确认低于 2 RPM；
  然后改变 DIR，再等待 10 ms 才恢复 PWM。编码器反馈不能缩短这 1000 ms。

`g_test.status` 只用于观察，不是控制变量；误改它不会暂停固件内部的超时和
故障保护。

## 5. 推荐调试与标定顺序

### A. 仅 MCU，不接电机电源

1. 断开 DRV8701E 的电机电源。
2. 编译、下载并复位。
3. 检查上述复位变量和 PA12、PA13，确认没有有效 PWM。

### B. 标定左右编码器 CPR 和方向

保持电机电源断开，编码器使用已验证的 5 V；四路 A/B 经电平转换后，
确认 MCU 侧高电平不超过 3.3 V。

1. 写 `g_test.mode = 2` 清零。
2. 写 `g_test.mode = 1` 进入观察模式。
3. 给左轮做标记，沿车辆前进方向精确手转输出轮一整圈。
4. 记录 `g_test.left.encoder_count`。
5. 再次清零，对右轮重复，记录 `g_test.right.encoder_count`。
6. 每侧至少重复数次，使用实测绝对值，而不是只按 13 PPR 理论计算。

2026-07-25 的四组十圈测量结果为：左轮平均 1467.475 counts/rev，右轮平均
1467.95 counts/rev；版本 2026072504 分别取左1467、右1468。更换编码器或
减速箱后需要重新测量。左右实测值分别写入
`chassis_config.h`：

```c
ENCODER_LEFT_COUNTS_PER_WHEEL_REV
ENCODER_RIGHT_COUNTS_PER_WHEEL_REV
```

车辆前进方向手转时，修正后的累计值应为正。若为负，只修改对应的
`ENCODER_*_REVERSED` 标志后重测，不要同时改多个方向标志来掩盖接错线。

慢速手转时 `g_test.left_invalid_transitions` 应接近零；若快速增加，应检查
噪声、上下拉配置和软件解码漏边沿。

### C. 不接电机电源，检查 PWM/DIR

1. 断开全部电源，用万用表蜂鸣档逐根确认：
   PA12/BP32 只到 PWM1，PB4/BP40 只到 DIR1，
   PA13/BP31 只到 PWM2，PB1/BP39 只到 DIR2。
2. 只连接 DRV 的 GND、PWM1、DIR1、PWM2、DIR2，保持电机 12 V 断开。
3. 只用 USB 启动，在 mode 0 测得 PA12、PA13、PB4、PB1 全部为 0 V。
4. 设置 `g_test.duration_ms = 2000`；开环诊断固定使用 15% PWM。
5. 按固定下发顺序运行模式 3，确认只有 PA12 输出 20 kHz、10% PWM。
6. 改回 mode 0，确认四根控制线都在 10 ms 内回到 0 V。
7. 再运行模式 4，确认只有 PA13 输出 PWM，并重复 mode 0 全低测试。
8. 用示波器确认 DIR 只在 PWM 已撤掉时改变，并符合 1000 ms 滑行和
   10 ms DIR 建立时间。

### D. 悬空车轮，首次电机测试

1. 固定底盘，使两个驱动轮都离地。
2. 先把降压模块输出调到实测 12.0 V，再连接 DRV 电机电源。
3. 从 `open_pwm = 10` 开始，不要从 30% 开始。
4. 分别运行模式 3、4，再短暂运行模式 5。
5. 正向 PWM 必须使对应车轮向车辆前进方向转动，同时修正后的编码器计数增加。

若电机方向错误，只修改对应的 `MOTOR_*_OUTPUT_REVERSED`，或明确交换该电机
两根动力线，并记录实际采用的方案。

### E. 转速闭环和 PID

只有 CPR、编码器方向和电机方向全部正确后才调 PID。

1. 设置 `target_rpm = 40`、`duration_ms = 5000`。
2. 按固定顺序运行模式 7。
3. 同时观察 `g_test.left/right` 中的 `rpm`、`error_rpm`、`pwm`、
   `integral` 和 `pid_output`。
4. 只在停止状态修改 `g_test.left/right.kp/ki/kd`，新参数会在下一次
   模式 7 启动时生效。

初始参数仅为起点：

```text
Kp = 0.7
Ki = 20.0
Kd = 0.0
控制周期 = 0.010 s
```

若状态为 `-4`，先停止并检查方向标志、接线、供电、信号质量或机械卡滞，
不要通过增大 PWM 绕过故障。固件内部 40% 闭环上限不可通过 WATCH 修改。
最终左右 PID 参数应记录到 `AGENT.MD`。

### F. 落地距离与转向标定

距离和转角命令模式暂缓，等编码器计数与模式 7 PID 调试通过后再加入。

### G. KEY1 独立启动

build `2026073005` 只使用八键板的 SW1。接线：

- `SW1 -> PA10/BP33`；
- `GND -> 系统 GND`；
- `VCC -> LaunchPad 3V3`，禁止接 5V；
- `SW2-SW8` 均不接。
- J21、J22 保持在 `BP`/BoosterPack 一侧。

PA10 使用 MSPM0 内部上拉，松开为高电平、按下接地为低电平。固件每
10 ms 轮询并进行 40 ms 消抖：

VCC 悬空时用户实测松开只有 2.16 V、按下 0 V；松开电平不合格。VCC 改接
3V3 后，必须先复测松开约 3.3 V、按下约 0 V，再接通电机电源。

1. 按下并松开 KEY1，本地倒计时 3 秒，倒计时期间电机保持关闭；
2. 倒计时结束后仍须在 500 ms 内收到连续 5 个启动后新采集的有效红外
   样本，才允许 `Motor_Arm()`；
4. 启动后先以 30 RPM 基速慢行 1 秒，再平滑升至前 300 mm 的 55 RPM
   限制，随后Q1正式场地直线基速最高 143 RPM、弯道基速最低 110 RPM，
   转向 Kp 12、Kd 6；本地运行总超时固定 20000 ms；
4. 倒计时或运行期间再按一次 KEY1，立即取消/停车；
5. `STANDALONE_KEY1_START=1` 是当前临时选择；以后需要 MC02 时改为 0，
   再恢复 PREPARE/READY/START 为唯一启动授权。

SW2-SW8 与板载 S2 当前均无功能，所以 K7/K8 本地停车还未实现。物理总
开关必须始终可触及。

### H. 蓝牙暂时停用

JDY-31 已拔掉。build `2026073005` 不生成 UART0，也不编译或调用
`bluetooth.c`；PA10 已改作 SW1。蓝牙源文件和电脑脚本仅作为以后恢复时的
参考保留，当前固件不能接收任何蓝牙命令。

### I. 幻尔 8 路巡线与低速循迹

`2026073005` 在已验证的传感器采集上通过 KEY1 本地启动比赛循迹模式 8：

1. 电机电源保持断开，先不要接 PB2/PB3；
2. 模块 `5V` 接稳定 5 V 辅助电源，`GND` 接系统公共地；
3. 模块单独上电后，分别测 `SCL`、`SDA` 对 GND 的空闲电压；
4. 两路都不高于 3.3 V 时，断电后接 `SCL -> PB2/BP9`、
   `SDA -> PB3/BP10`；若任一路高于 3.3 V，必须加双向 I2C 电平转换；
5. 下载固件，保持 `g_test.mode = 0`，在 WATCH 展开 `g_test.line`；
6. `connected = 1` 且 `sample_sequence` 持续增加，表示 I2C 通信正常；
7. 固定安装高度并按模块 KEY 完成“背景长按学习、目标线短按学习”；
8. 逐个移动 S1-S8，记录 `state` 位序、`analog[0..7]`、
   `threshold[0..7]`，并确认车头朝前时 S1 在物理左侧还是右侧。

已实测确认白底 `state=0`、S1 黑线 `state=1`、S8 黑线 `state=128`，
即 bit0=S1（车左）、bit7=S8（车右），置位代表黑线。

首次运动检查必须架空驱动轮，同时保持传感器与测试纸的标定高度，然后
按下 KEY1 启动。

1. 黑线位于 S4/S5 时两轮转速应接近相等；移向 S1 时左轮变慢、右轮变快；
   移向 S8 时相反；
2. 巡线位置先以 0.25 系数低通后再参与弯道调速与 PD 计算，避免数字通道
   切换造成速度阶跃。短暂丢线的前 50 ms 保持原目标，随后才按最后一次
   线路所在方向以 45 RPM 基速和 28 RPM 差速搜线；300 ms 内重新检测到线
   则恢复，持续超过 300 ms 才停车并保留 `status=-6`。I2C 断开或数据停止
   更新仍立即撤掉目标，并在 100 ms 内报错停车；
3. 再按一次 KEY1 必须能提前停车。

模式 8 延用模式 7 的轮速 PID、编码器监督、PWM 限幅和到时停车。正式场地
由两段 1.5 m 直线和两个半径 0.5 m 的半圆组成，中心线总长
`2×1.5+2π×0.5=6.1416 m`，外廓约 2.5 m × 1.0 m。65 mm 轮径下，
20 秒纯匀速理论下限约 90.2 RPM；当前正式版Q1使用 143 RPM 直线基速和
110 RPM 弯道最低基速。比赛时把车头阵列放在起点
横向长黑线上，按 KEY1 启动；程序先倒计时 3 秒并确认连续 5 个新红外采样，
再以 30 RPM 慢行；起点横线后的前 100 mm 左右轮保持相同目标，随后才启用
灰度重心转向并逐步提速。完成一圈后，编码器航向累计和距离只负责进入停车
流程：程序以 60 RPM 继续循迹 150～250 mm，要求普通直线连续 8 个新采样
保持居中且只亮 1～2 路，然后真正零 PWM，待双轮降到 2 RPM 以下，再以
左右相同的 25 RPM 低速倒车。倒车时统计最近 120 ms 的通道位图并集；
并集至少覆盖 4 个不同通道、左右半区均出现并连续确认 2 个新采样，才认定
循迹模块到达终点横线并立即失能停车。倒车超过 400 mm 或 6 秒仍未找到横线
则按超时安全停车，不允许继续第二圈。当前距离
换算使用 65.0 mm 轮径及左右 1467/1468 CPR，首次场地测试必须用尺测量实际
停车偏差和总用时，再按实测结果修正。传感器、编码器或输出发生故障仍会提前停车；
再按 KEY1 也可随时提前停止。

204.7 mm 前后轴距不进入理想两轮差速公式，但会通过万向轮阻力和打滑影响
实际转向，因此最终轮距必须在整车装配并加载后实测标定。

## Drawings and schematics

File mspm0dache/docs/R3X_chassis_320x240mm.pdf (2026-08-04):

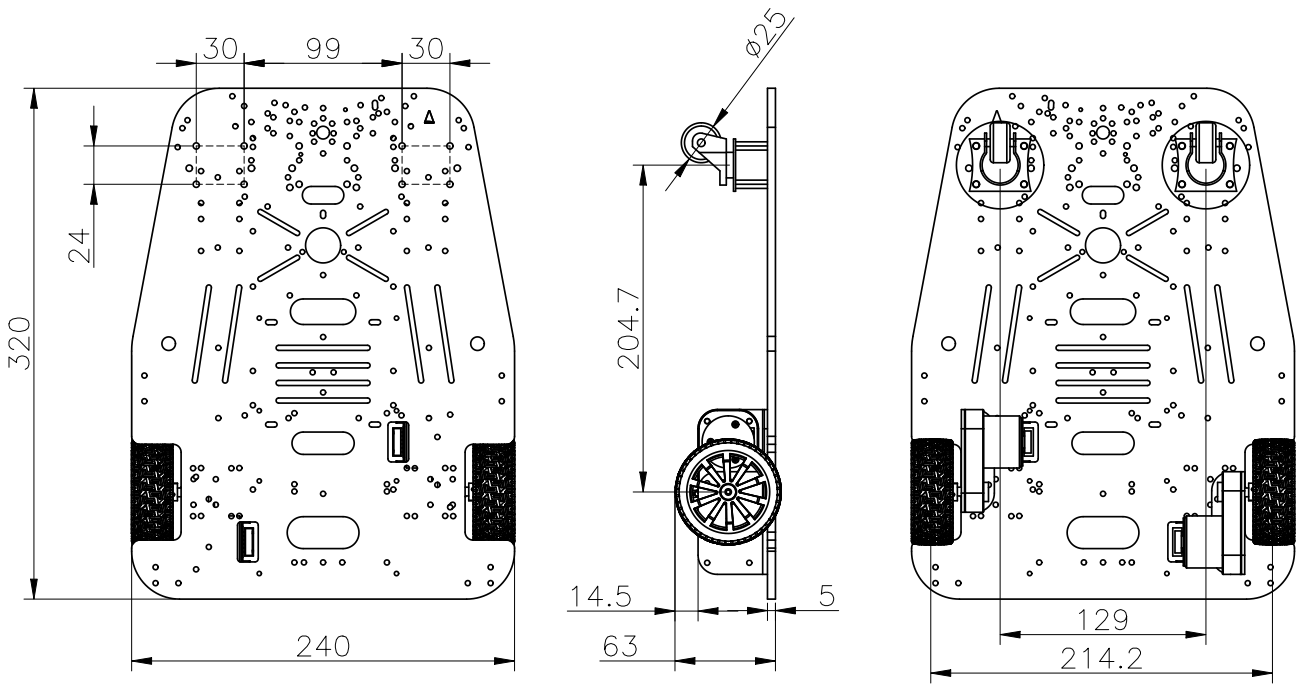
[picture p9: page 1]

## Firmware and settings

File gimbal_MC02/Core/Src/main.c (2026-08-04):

#include "main.h"
#include "fdcan.h"
#include "gpio.h"
#include "usb_device.h"
#include "gimbal_app.h"
#include "jetson_link.h"
#include "ti_link.h"
#include "usb_console.h"

void SystemClock_Config(void);

int main(void)
{
    HAL_Init();
    SystemClock_Config();

    /*
     * MX_GPIO_Init explicitly keeps PC13/PC14 low/off.  The application may
     * later enable OUT1/PC14 only through its armed, time-limited bench path.
     * OUT2/PC13 remains off.
     */
    MX_GPIO_Init();
    MX_FDCAN1_Init();

    usb_console_init();
    MX_USB_DEVICE_Init();
    gimbal_app_init(HAL_GetTick());
    jetson_link_init(HAL_GetTick());
    ti_link_init(HAL_GetTick());

    while (1)
    {
        uint32_t now_ms = HAL_GetTick();
        jetson_link_poll(now_ms);
        ti_link_poll(now_ms);
        gimbal_app_poll(now_ms);
    }
}

void SystemClock_Config(void)
{
    RCC_OscInitTypeDef RCC_OscInitStruct = {0};
    RCC_ClkInitTypeDef RCC_ClkInitStruct = {0};

    HAL_PWREx_ConfigSupply(PWR_LDO_SUPPLY);
    __HAL_PWR_VOLTAGESCALING_CONFIG(PWR_REGULATOR_VOLTAGE_SCALE0);
    while (!__HAL_PWR_GET_FLAG(PWR_FLAG_VOSRDY))
    {
    }

    RCC_OscInitStruct.OscillatorType =
        RCC_OSCILLATORTYPE_HSI48 |
        RCC_OSCILLATORTYPE_HSI |
        RCC_OSCILLATORTYPE_HSE;
    RCC_OscInitStruct.HSEState = RCC_HSE_ON;
    RCC_OscInitStruct.HSIState = RCC_HSI_DIV1;
    RCC_OscInitStruct.HSICalibrationValue = 64;
    RCC_OscInitStruct.HSI48State = RCC_HSI48_ON;
    RCC_OscInitStruct.PLL.PLLState = RCC_PLL_ON;
    RCC_OscInitStruct.PLL.PLLSource = RCC_PLLSOURCE_HSE;
    RCC_OscInitStruct.PLL.PLLM = 2;
    RCC_OscInitStruct.PLL.PLLN = 40;
    RCC_OscInitStruct.PLL.PLLP = 1;
    RCC_OscInitStruct.PLL.PLLQ = 4;
    RCC_OscInitStruct.PLL.PLLR = 2;
    RCC_OscInitStruct.PLL.PLLRGE = RCC_PLL1VCIRANGE_3;
    RCC_OscInitStruct.PLL.PLLVCOSEL = RCC_PLL1VCOWIDE;
    RCC_OscInitStruct.PLL.PLLFRACN = 0;
    if (HAL_RCC_OscConfig(&RCC_OscInitStruct) != HAL_OK)
    {
        Error_Handler();
    }

    RCC_ClkInitStruct.ClockType =
        RCC_CLOCKTYPE_HCLK |
        RCC_CLOCKTYPE_SYSCLK |
        RCC_CLOCKTYPE_PCLK1 |
        RCC_CLOCKTYPE_PCLK2 |
        RCC_CLOCKTYPE_D3PCLK1 |
        RCC_CLOCKTYPE_D1PCLK1;
    RCC_ClkInitStruct.SYSCLKSource = RCC_SYSCLKSOURCE_PLLCLK;
    RCC_ClkInitStruct.SYSCLKDivider = RCC_SYSCLK_DIV1;
    RCC_ClkInitStruct.AHBCLKDivider = RCC_HCLK_DIV2;
    RCC_ClkInitStruct.APB3CLKDivider = RCC_APB3_DIV2;
    RCC_ClkInitStruct.APB1CLKDivider = RCC_APB1_DIV2;
    RCC_ClkInitStruct.APB2CLKDivider = RCC_APB2_DIV2;
    RCC_ClkInitStruct.APB4CLKDivider = RCC_APB4_DIV2;

    if (HAL_RCC_ClockConfig(&RCC_ClkInitStruct, FLASH_LATENCY_3) != HAL_OK)
    {
        Error_Handler();
    }
    HAL_RCC_MCOConfig(RCC_MCO1, RCC_MCO1SOURCE_HSI, RCC_MCODIV_1);
}

void HAL_TIM_PeriodElapsedCallback(TIM_HandleTypeDef *htim)
{
    if (htim->Instance == TIM23)
    {
        HAL_IncTick();
    }
}

void Error_Handler(void)
{
    __disable_irq();
    while (1)
    {
    }
}

#ifdef USE_FULL_ASSERT
void assert_failed(uint8_t *file, uint32_t line)
{
    (void)file;
    (void)line;
}
#endif

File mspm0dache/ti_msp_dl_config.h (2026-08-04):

/*
 * Copyright (c) 2023, Texas Instruments Incorporated - http://www.ti.com
 * All rights reserved.
 *
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
 * *  Redistributions of source code must retain the above copyright
 *    notice, this list of conditions and the following disclaimer.
 *
 * *  Redistributions in binary form must reproduce the above copyright
 *    notice, this list of conditions and the following disclaimer in the
 *    documentation and/or other materials provided with the distribution.
 *
 * *  Neither the name of Texas Instruments Incorporated nor the names of
 *    its contributors may be used to endorse or promote products derived
 *    from this software without specific prior written permission.
 *
 * THIS SOFTWARE IS PROVIDED BY THE COPYRIGHT HOLDERS AND CONTRIBUTORS "AS IS"
 * AND ANY EXPRESS OR IMPLIED WARRANTIES, INCLUDING, BUT NOT LIMITED TO,
 * THE IMPLIED WARRANTIES OF MERCHANTABILITY AND FITNESS FOR A PARTICULAR
 * PURPOSE ARE DISCLAIMED. IN NO EVENT SHALL THE COPYRIGHT OWNER OR
 * CONTRIBUTORS BE LIABLE FOR ANY DIRECT, INDIRECT, INCIDENTAL, SPECIAL,
 * EXEMPLARY, OR CONSEQUENTIAL DAMAGES (INCLUDING, BUT NOT LIMITED TO,
 * PROCUREMENT OF SUBSTITUTE GOODS OR SERVICES; LOSS OF USE, DATA, OR PROFITS;
 * OR BUSINESS INTERRUPTION) HOWEVER CAUSED AND ON ANY THEORY OF LIABILITY,
 * WHETHER IN CONTRACT, STRICT LIABILITY, OR TORT (INCLUDING NEGLIGENCE OR
 * OTHERWISE) ARISING IN ANY WAY OUT OF THE USE OF THIS SOFTWARE,
 * EVEN IF ADVISED OF THE POSSIBILITY OF SUCH DAMAGE.
 */

/*
 *  ============ ti_msp_dl_config.h =============
 *  Configured MSPM0 DriverLib module declarations
 *
 *  DO NOT EDIT - This file is generated for the MSPM0G350X
 *  by the SysConfig tool.
 */
#ifndef ti_msp_dl_config_h
#define ti_msp_dl_config_h

#define CONFIG_MSPM0G350X
#define CONFIG_MSPM0G3507

#if defined(__ti_version__) || defined(__TI_COMPILER_VERSION__)
#define SYSCONFIG_WEAK __attribute__((weak))
#elif defined(__IAR_SYSTEMS_ICC__)
#define SYSCONFIG_WEAK __weak
#elif defined(__GNUC__)
#define SYSCONFIG_WEAK __attribute__((weak))
#endif

#include <ti/devices/msp/msp.h>
#include <ti/driverlib/driverlib.h>
#include <ti/driverlib/m0p/dl_core.h>

#ifdef __cplusplus
extern "C" {
#endif

/*
 *  ======== SYSCFG_DL_init ========
 *  Perform all required MSP DL initialization
 *
 *  This function should be called once at a point before any use of
 *  MSP DL.
 */


/* clang-format off */

#define POWER_STARTUP_DELAY                                                (16)



#define CPUCLK_FREQ                                                     32000000



/* Defines for MOTOR_PWM */
#define MOTOR_PWM_INST                                                     TIMG0
#define MOTOR_PWM_INST_IRQHandler                               TIMG0_IRQHandler
#define MOTOR_PWM_INST_INT_IRQN                                 (TIMG0_INT_IRQn)
#define MOTOR_PWM_INST_CLK_FREQ                                         32000000
/* GPIO defines for channel 0 */
#define GPIO_MOTOR_PWM_C0_PORT                                             GPIOA
#define GPIO_MOTOR_PWM_C0_PIN                                     DL_GPIO_PIN_12
#define GPIO_MOTOR_PWM_C0_IOMUX                                  (IOMUX_PINCM34)
#define GPIO_MOTOR_PWM_C0_IOMUX_FUNC                 IOMUX_PINCM34_PF_TIMG0_CCP0
#define GPIO_MOTOR_PWM_C0_IDX                                DL_TIMER_CC_0_INDEX
/* GPIO defines for channel 1 */
#define GPIO_MOTOR_PWM_C1_PORT                                             GPIOA
#define GPIO_MOTOR_PWM_C1_PIN                                     DL_GPIO_PIN_13
#define GPIO_MOTOR_PWM_C1_IOMUX                                  (IOMUX_PINCM35)
#define GPIO_MOTOR_PWM_C1_IOMUX_FUNC                 IOMUX_PINCM35_PF_TIMG0_CCP1
#define GPIO_MOTOR_PWM_C1_IDX                                DL_TIMER_CC_1_INDEX




/* Defines for QEI_RIGHT */
#define QEI_RIGHT_INST                                                     TIMG8
#define QEI_RIGHT_INST_IRQHandler                               TIMG8_IRQHandler
#define QEI_RIGHT_INST_INT_IRQN                                 (TIMG8_INT_IRQn)
/* Pin configuration defines for QEI_RIGHT PHA Pin */
#define GPIO_QEI_RIGHT_PHA_PORT                                            GPIOB
#define GPIO_QEI_RIGHT_PHA_PIN                                     DL_GPIO_PIN_6
#define GPIO_QEI_RIGHT_PHA_IOMUX                                 (IOMUX_PINCM23)
#define GPIO_QEI_RIGHT_PHA_IOMUX_FUNC                IOMUX_PINCM23_PF_TIMG8_CCP0
/* Pin configuration defines for QEI_RIGHT PHB Pin */
#define GPIO_QEI_RIGHT_PHB_PORT                                            GPIOB
#define GPIO_QEI_RIGHT_PHB_PIN                                     DL_GPIO_PIN_7
#define GPIO_QEI_RIGHT_PHB_IOMUX                                 (IOMUX_PINCM24)
#define GPIO_QEI_RIGHT_PHB_IOMUX_FUNC                IOMUX_PINCM24_PF_TIMG8_CCP1
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

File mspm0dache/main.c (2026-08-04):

#include <stdint.h>

#include "imu.h"
#include "line_sensor.h"
#include "mc02_link.h"
#include "motor.h"
#include "platform.h"
#include "question_timer.h"
#include "test_mode.h"
#include "ti_msp_dl_config.h"

#define TEST_TASK_PERIOD_MS 10U

static int task_due(uint32_t now, uint32_t *last, uint32_t period)
{
    if ((uint32_t) (now - *last) < period) {
        return 0;
    }
    *last += period;
    if ((uint32_t) (now - *last) >= period) {
        *last = now;
    }
    return 1;
}

int main(void)
{
    SYSCFG_DL_init();
    Platform_InitTick();

    Motor_Init();
    Imu_Init();
    LineSensor_Init();
    QuestionTimer_Init();
    TestMode_Init();
    MC02Link_Init();

    DL_GPIO_clearInterruptStatus(GPIO_ENCODER_LEFT_PORT,
        GPIO_ENCODER_LEFT_ENCODER_LEFT_A_PIN |
            GPIO_ENCODER_LEFT_ENCODER_LEFT_B_PIN);
    NVIC_ClearPendingIRQ(GPIO_ENCODER_LEFT_INT_IRQN);
    NVIC_EnableIRQ(GPIO_ENCODER_LEFT_INT_IRQN);

    uint32_t now = Platform_Millis();
    uint32_t last_motor = now;
    uint32_t last_test = now;

    for (;;) {
        now = Platform_Millis();

        if (task_due(now, &last_motor, MOTOR_CTRL_PERIOD_MS)) {
            Motor_ControlTick();
        }
        if (task_due(now, &last_test, TEST_TASK_PERIOD_MS)) {
            LineSensor_Tick();
            TestMode_Tick();
            MC02Link_Tick();
            Imu_Tick();
            QuestionTimer_Tick();
        }

        __WFI();
    }
}

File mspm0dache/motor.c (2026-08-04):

#include "motor.h"

#include <float.h>

#include "platform.h"
#include "ti_msp_dl_config.h"

static Motor_TypeDef g_motor[MOTOR_NUM];

static volatile uint32_t s_left_encoder_raw;
static volatile uint8_t s_left_encoder_state;
static volatile uint32_t s_left_encoder_invalid_transitions;
static volatile uint8_t s_motor_armed;
static uint8_t s_pwm_timer_pin_mask;
static uint32_t s_pwm_period_counts;
static int8_t s_raw_direction[MOTOR_NUM];
static int8_t s_pending_direction[MOTOR_NUM];
static uint8_t s_direction_phase[MOTOR_NUM];
static uint32_t s_direction_phase_start_ms[MOTOR_NUM];

enum {
    DIRECTION_PHASE_IDLE = 0,
    DIRECTION_PHASE_COAST,
    DIRECTION_PHASE_SETUP
};

#define PWM_TIMER_PIN_RIGHT (1U << MOTOR_RIGHT)
#define PWM_TIMER_PIN_LEFT  (1U << MOTOR_LEFT)
#define PWM_TIMER_PIN_ALL   (PWM_TIMER_PIN_RIGHT | PWM_TIMER_PIN_LEFT)

static const uint32_t s_counts_per_wheel_rev[MOTOR_NUM] = {
    [MOTOR_RIGHT] = ENCODER_RIGHT_COUNTS_PER_WHEEL_REV,
    [MOTOR_LEFT] = ENCODER_LEFT_COUNTS_PER_WHEEL_REV,
};

/* Index: previous AB in bits 3:2, current AB in bits 1:0. */
static const int8_t s_quadrature_delta[16] = {
     0, -1,  1,  0,
     1,  0,  0, -1,
    -1,  0,  0,  1,
     0,  1, -1,  0,
};

static int float_is_finite(float value)
{
    return value == value && value <= FLT_MAX && value >= -FLT_MAX;
}

static float abs_float(float value)
{
    return value < 0.0f ? -value : value;
}

static void pid_reset(PID_TypeDef *pid)
{
    pid->integral = 0.0f;
    pid->prev_error = 0.0f;
    pid->output = 0.0f;
}

static void pid_init(PID_TypeDef *pid)
{
    /*
     * Provisional values equivalent to the old 10 ms controller, expressed
     * with integral units in seconds. Retune on the loaded chassis.
     */
    pid->kp = MOTOR_PID_DEFAULT_KP;
    pid->ki = MOTOR_PID_DEFAULT_KI;
    pid->kd = MOTOR_PID_DEFAULT_KD;
    pid->integral_max = 6.0f;
    pid->out_max = MOTOR_CLOSED_LOOP_PWM_LIMIT;
    pid->out_min = -MOTOR_CLOSED_LOOP_PWM_LIMIT;
    pid_reset(pid);
}

static void force_pwm_pin_low(Motor_ID id);
static void connect_pwm_pin_to_timer(Motor_ID id);

static uint8_t read_left_encoder_state(void)
{
    uint32_t pins = DL_GPIO_readPins(GPIO_ENCODER_LEFT_PORT,
        GPIO_ENCODER_LEFT_ENCODER_LEFT_A_PIN |
            GPIO_ENCODER_LEFT_ENCODER_LEFT_B_PIN);
    uint8_t state = 0U;

    if ((pins & GPIO_ENCODER_LEFT_ENCODER_LEFT_A_PIN) != 0U) {
        state |= 2U;
    }
    if ((pins & GPIO_ENCODER_LEFT_ENCODER_LEFT_B_PIN) != 0U) {
        state |= 1U;
    }
    return state;
}

static void set_pwm_percent(Motor_ID id, uint16_t duty_percent)
{
    if (duty_percent > (uint16_t) MOTOR_PWM_MAX) {
        duty_percent = (uint16_t) MOTOR_PWM_MAX;
    }

    if (s_pwm_period_counts == 0U) {
        return;
    }

    /*
     * In this down-count edge-aligned configuration, LOAD drives CCP high
     * and a compare-down event drives it low. A compare value equal to the
     * period is outside the counter range, so it produces constant high,
     * not zero duty. A true 0% command must therefore use GPIO-low.
     */
    if (duty_percent == 0U) {
        force_pwm_pin_low(id);
        return;
    }

    uint32_t compare = s_pwm_period_counts -
        ((s_pwm_period_counts * (uint32_t) duty_percent) / 100U);
    DL_TIMER_CC_INDEX channel = (id == MOTOR_RIGHT) ?
        GPIO_MOTOR_PWM_C0_IDX : GPIO_MOTOR_PWM_C1_IDX;
    DL_TimerG_setCaptureCompareValue(MOTOR_PWM_INST, compare, channel);
    connect_pwm_pin_to_timer(id);
}

static void set_direction(Motor_ID id, int direction)
{
    uint32_t pin = (id == MOTOR_RIGHT) ?
        GPIO_MOTOR_RIGHT_DIR_PIN : GPIO_MOTOR_LEFT_DIR_PIN;

    if (direction > 0) {
        DL_GPIO_setPins(GPIO_MOTOR_PORT, pin);
    } else {
        DL_GPIO_clearPins(GPIO_MOTOR_PORT, pin);
    }
}

static void force_outputs_off(void)
{
    if (s_pwm_period_counts == 0U) {
        return;
    }
    DL_TimerG_setCaptureCompareValue(MOTOR_PWM_INST,
        s_pwm_period_counts, GPIO_MOTOR_PWM_C0_IDX);
    DL_TimerG_setCaptureCompareValue(MOTOR_PWM_INST,
        s_pwm_period_counts, GPIO_MOTOR_PWM_C1_IDX);
}

static void force_pwm_pin_low(Motor_ID id)
{
    uint8_t mask = (id == MOTOR_RIGHT) ?
        PWM_TIMER_PIN_RIGHT : PWM_TIMER_PIN_LEFT;
    GPIO_Regs *port = (id == MOTOR_RIGHT) ?
        GPIO_MOTOR_PWM_C0_PORT : GPIO_MOTOR_PWM_C1_PORT;
    uint32_t pin = (id == MOTOR_RIGHT) ?
        GPIO_MOTOR_PWM_C0_PIN : GPIO_MOTOR_PWM_C1_PIN;
    uint32_t iomux = (id == MOTOR_RIGHT) ?
        GPIO_MOTOR_PWM_C0_IOMUX : GPIO_MOTOR_PWM_C1_IOMUX;
    DL_TIMER_CC_INDEX channel = (id == MOTOR_RIGHT) ?
        GPIO_MOTOR_PWM_C0_IDX : GPIO_MOTOR_PWM_C1_IDX;

    DL_TimerG_setCaptureCompareValue(
        MOTOR_PWM_INST, s_pwm_period_counts, channel);
    DL_GPIO_clearPins(port, pin);
    if ((s_pwm_timer_pin_mask & mask) != 0U) {
        DL_GPIO_initDigitalOutput(iomux);
        DL_GPIO_enableOutput(port, pin);
        s_pwm_timer_pin_mask &= (uint8_t) ~mask;
    }
    DL_GPIO_clearPins(port, pin);
}

static void connect_pwm_pin_to_timer(Motor_ID id)
{
    uint8_t mask = (id == MOTOR_RIGHT) ?
        PWM_TIMER_PIN_RIGHT : PWM_TIMER_PIN_LEFT;

    if ((s_pwm_timer_pin_mask & mask) != 0U) {
        return;
    }

    if (id == MOTOR_RIGHT) {
        DL_GPIO_initPeripheralOutputFunction(
            GPIO_MOTOR_PWM_C0_IOMUX, GPIO_MOTOR_PWM_C0_IOMUX_FUNC);
        DL_GPIO_enableOutput(
            GPIO_MOTOR_PWM_C0_PORT, GPIO_MOTOR_PWM_C0_PIN);
    } else {
        DL_GPIO_initPeripheralOutputFunction(
            GPIO_MOTOR_PWM_C1_IOMUX, GPIO_MOTOR_PWM_C1_IOMUX_FUNC);
        DL_GPIO_enableOutput(
            GPIO_MOTOR_PWM_C1_PORT, GPIO_MOTOR_PWM_C1_PIN);
    }
    s_pwm_timer_pin_mask |= mask;
}

/*
 * Disarming must produce a physical low level even if the timer is halted,
 * misconfigured, or the external PWM/DIR wires have accidentally been
 * crossed. Disconnect both CCP functions from the pins and drive all four
 * motor-control signals low.
 */
static void force_control_pins_low(void)
{
    force_outputs_off();
    force_pwm_pin_low(MOTOR_RIGHT);
    force_pwm_pin_low(MOTOR_LEFT);
    DL_GPIO_clearPins(GPIO_MOTOR_PORT,
        GPIO_MOTOR_RIGHT_DIR_PIN | GPIO_MOTOR_LEFT_DIR_PIN);
}

static void cancel_direction_transition(Motor_ID id)
{
    s_pending_direction[id] = 0;
    s_direction_phase[id] = DIRECTION_PHASE_IDLE;
    s_direction_phase_start_ms[id] = 0U;
    set_direction(id, s_raw_direction[id]);
}
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
